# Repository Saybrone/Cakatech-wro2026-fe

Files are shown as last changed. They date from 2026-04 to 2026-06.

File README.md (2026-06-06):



# Team Çakatech - WRO® 2026 Future Engineers

<table border="0">
  <tr border="0">
    <td width="70%"  border="0">
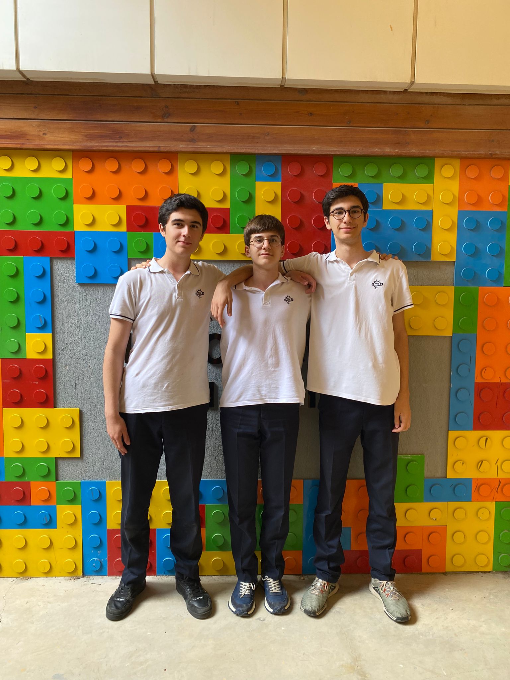
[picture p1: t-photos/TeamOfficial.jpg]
Official Photo
      
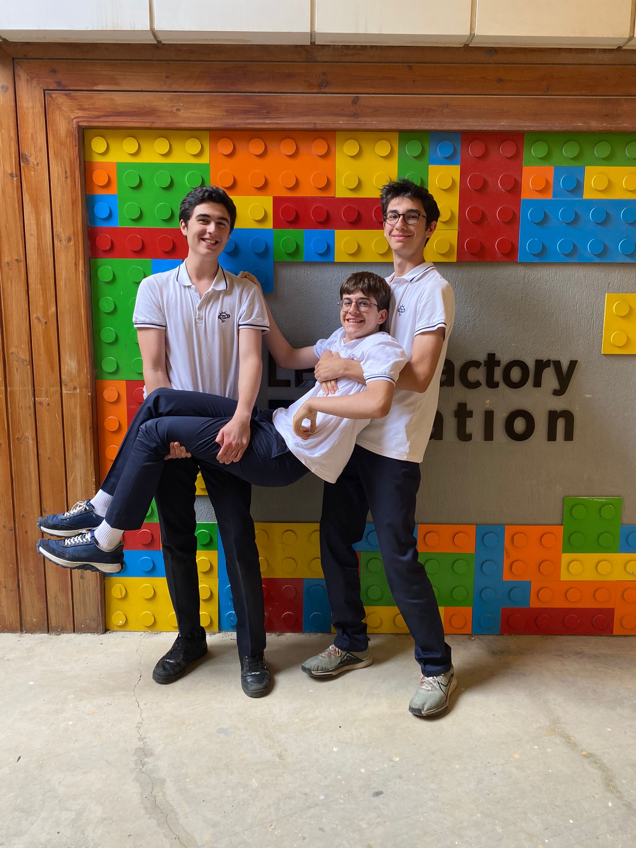
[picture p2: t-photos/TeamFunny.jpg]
Funny Photo
      
    </td>
    <td valign="top" style="padding-left: 0px;" border="0">
        This repository details team <em>Çakatech</em>'s building and programming process in the 2026 WRO Future Engineers Competition. 
      We are team <em>Çakatech</em>, three students who are passionate about technology and robotics. For this competition we built an autonomous vehicle. We worked after school and on weekends. Through this competition, we learned how to work as a team and solve problems related to robotics.
       </p>
        <strong>Team Members:</strong>
      <ul>
        <li>Batuhan Pekcan, 16</li>
        <li>Deniz Türker, 16</li>
        <li>Ali Aslan İşkol, 15</li>
      </ul>
      </p>
    </td>
  </tr>
</table>



# Table of Contents
- [Folder Contents](#folder-contents)
- [The Challenge](#the-challenge)
- [Vehicle Overview](#vehicle-overview)
  - [V-Photos](#v-photos)
  - [Hardware Components](#hardware-components)
  - [Electronic Components](#electronic-components)
  - [Mobility Management](#mobility-management)
    - [Powertrain](#powertrain)
    - [Steering](#steering)
    - [Chassis](#chassis)
- [Power and Sense Management](#power-and-sense-management)
  - [Li-ion Battery](#li-ion-battery)
  - [IMU Sensor](#imu-sensor)
  - [OpenMV Cam RT1062](#camera)
  - [EVN Alpha](#evn-alpha)
- [Software Components](#software-components)
  - [EVN Alpha Side](#evnalpha-side)
  - [OpenMV Camera Side](#openmv-side)
- [License](#license)

# Folder Contents 
* `models` is for the 3D files we used to print our parts
* `other` includes other files which can be used to understand how to prepare the vehicle for the competition. It includes documentations, datasets, hardware specifications, communication protocols,  descriptions etc.
* `schemes` contains schematic diagrams of the electromechanical components illustrating all the elements (electronic components and motors) used in the vehicle and how they connect to each other.
* `src` contains code of control software for all components which were programmed to participate in the competition
* `t-photos` contains photos of the team and logos
* `v-photos` contains 6 photos of the vehicle from various angles
* `video` contains the video.md file with the link to our YouTube channel and the respective videos

# The Challenge 

In the **[WRO 2026 Future Engineers – Self-Driving Cars](https://wro-association.org/)** category, teams are tasked with creating a robotic vehicle that can autonomously navigate a changing racetrack. Each round introduces new track layouts, requiring vehicles to adapt in real time.
The competition highlights the full engineering process:

- **Vehicle Design**: Building a functional robot with electromechanical components and advanced steering or motion systems.
- **Obstacle Management**: Applying computer vision, sensor fusion, and motion planning to make real-time decisions.
- **Project Documentation**: Maintaining an engineering journal and sharing designs in a public GitHub repository.

Teams are judged on performance, innovation, reliability, and the clarity of their engineering process, encouraging creativity, teamwork, and STEM skills.

Learn more about the challenge [here](https://wro-association.org/wp-content/uploads/WRO-2026-Future-Engineers-Self-Driving-Cars-General-Rules.pdf).

# Vehicle 

## V-Photos <b class="anchor" id="v-photos"></a>
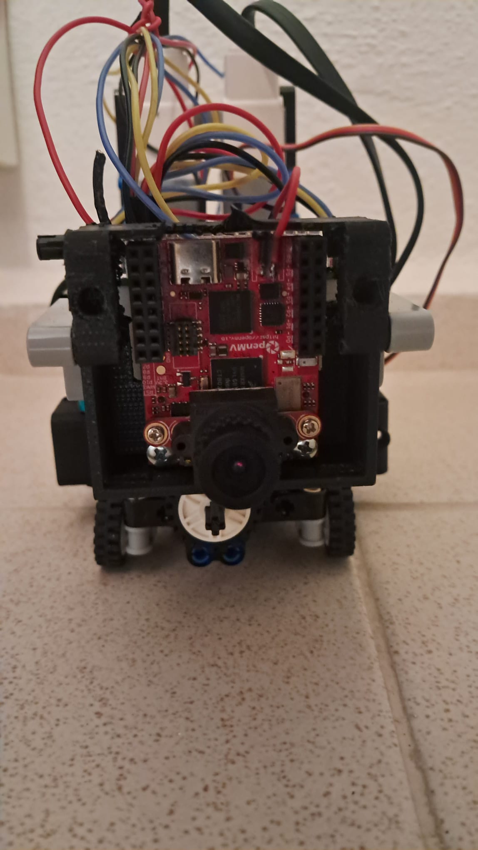
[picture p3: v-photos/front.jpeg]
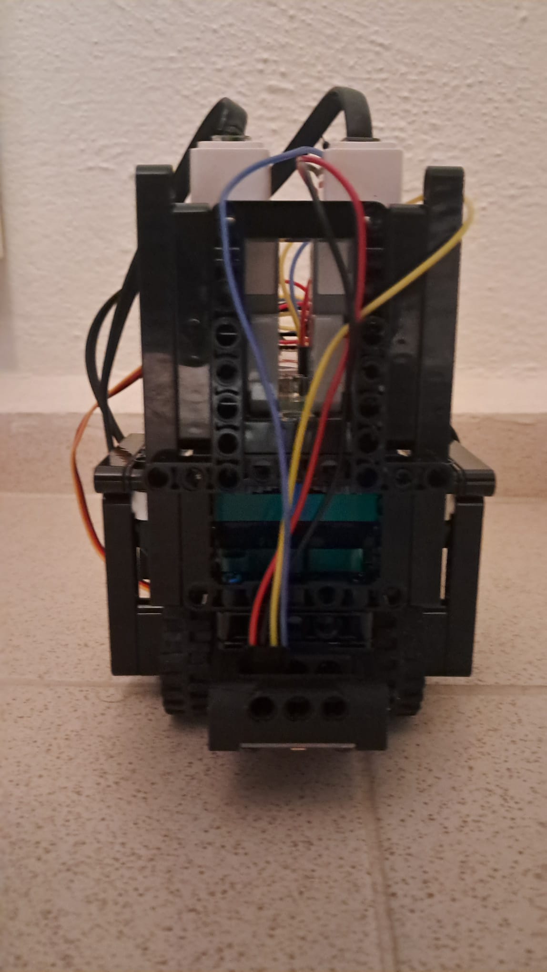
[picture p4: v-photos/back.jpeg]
|  |  | 
| :--: | :--: |
| *Front* | *Back* |
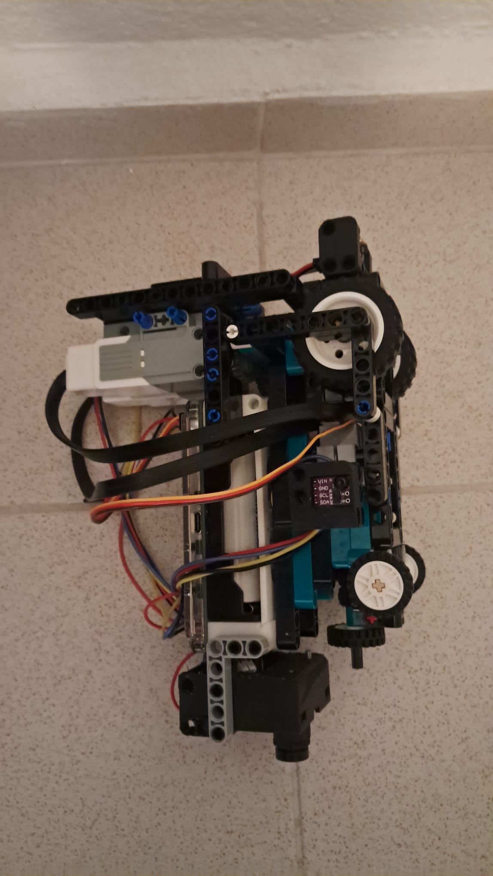
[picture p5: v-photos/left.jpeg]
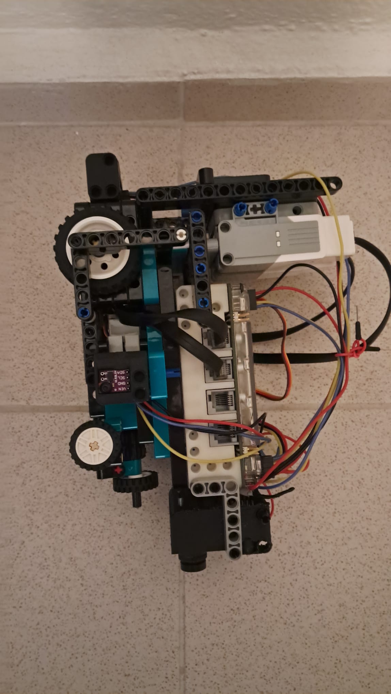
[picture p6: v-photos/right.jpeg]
|  |  | 
| *Left* | *Right* |
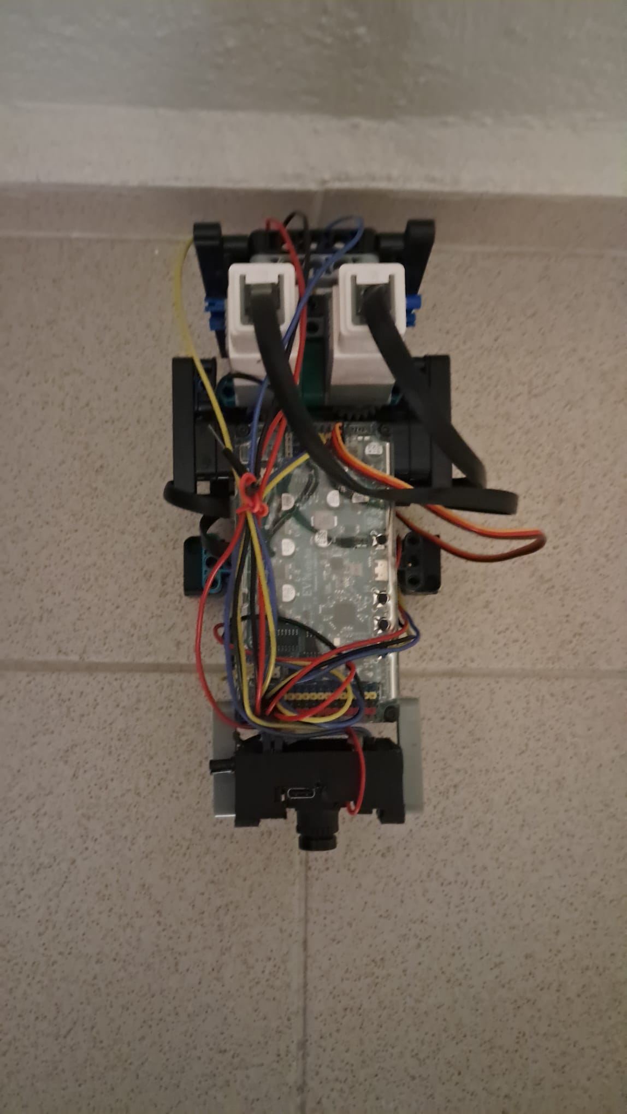
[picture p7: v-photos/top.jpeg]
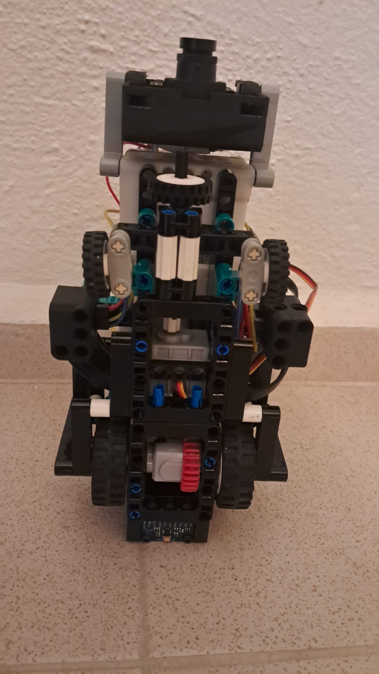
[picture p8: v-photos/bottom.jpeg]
|  |  | 
| *Top* | *Bottom* |

<br>

# Hardware Components 
This section covers all the parts utilized in the vehicle, such as motors, sensors, controllers, chassis, mechanical systems, and other components.
## Electronic Components 
<table border="1" cellpadding="12" cellspacing="0">
  <thead>
    <tr>
      <th>Component</th>
      <th>Description / Link</th>
      <th>Image</th>
      <th>Price</th>
    </tr>
  </thead>
  <tbody>
    <tr>
      <td>Motor</td>
      <td>EV3 Medium Motor</td>
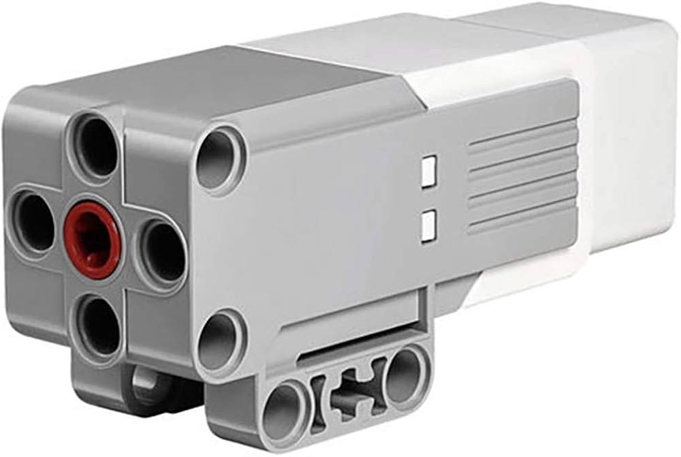
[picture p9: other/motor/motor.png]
Motor
      <td>
      <td>$125x2</td>
    </tr>
    <tr>
      <td>Servo Motor</td>
      <td>GeekServo (360 degrees)</a></td>
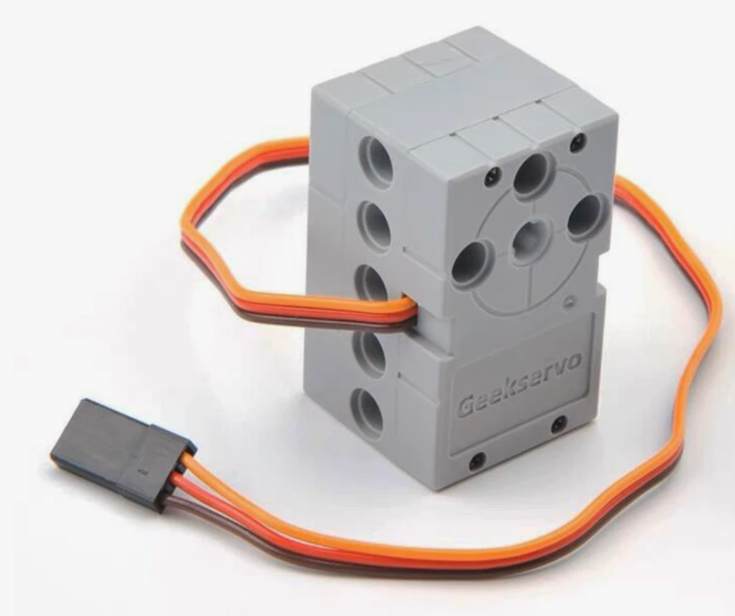
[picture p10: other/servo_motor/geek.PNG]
Servo motor
      <td>
      <td>$10</td>
    </tr>
  <tr>
    <tr>
      <td>Motor Controller and Processor</td>
      <td>EVN Alpha</a></td>
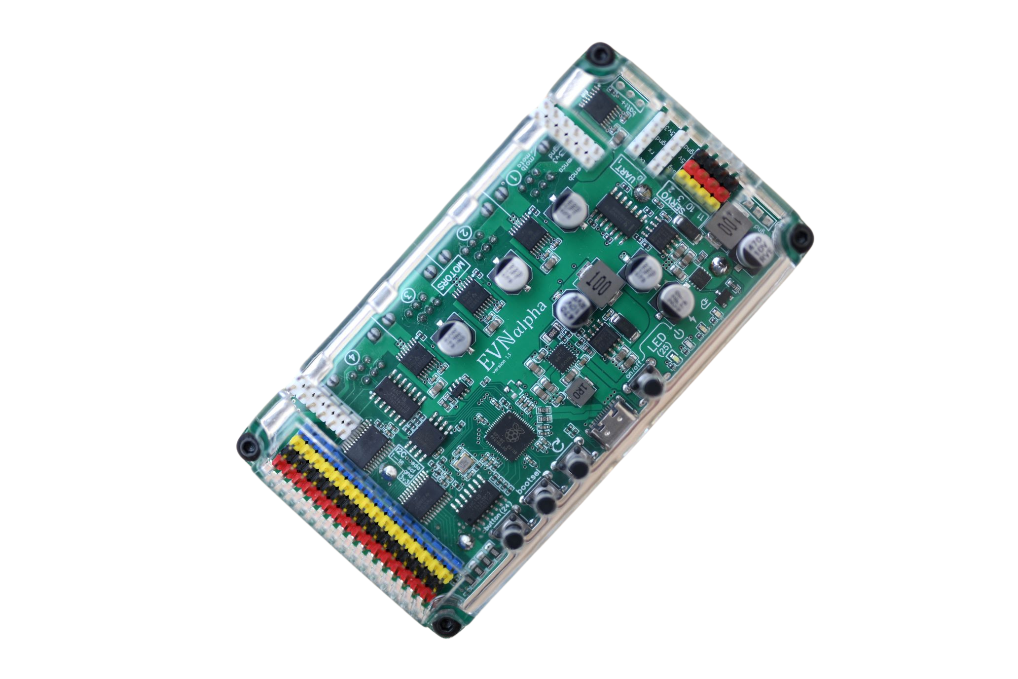
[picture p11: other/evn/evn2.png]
evn
      <td></td>
      <td>$168</td>
    </tr>
      <td>IMU</td>
      <td>MPU 6500 Gyro Sensor</td>
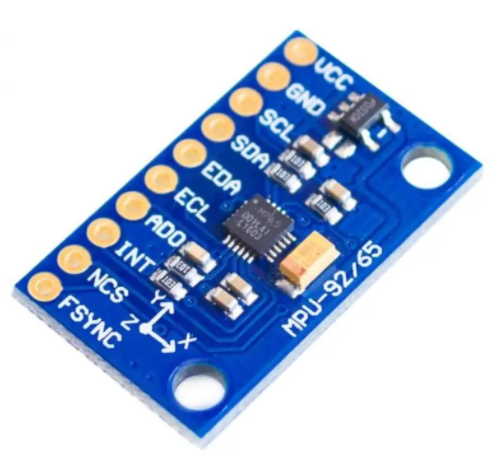
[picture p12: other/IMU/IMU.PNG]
IMU
      <td>
      <td>$1.88</td> 
    <tr>
      <td>Battery</td>
      <td>Molicel 35A Li-ion battery</td>
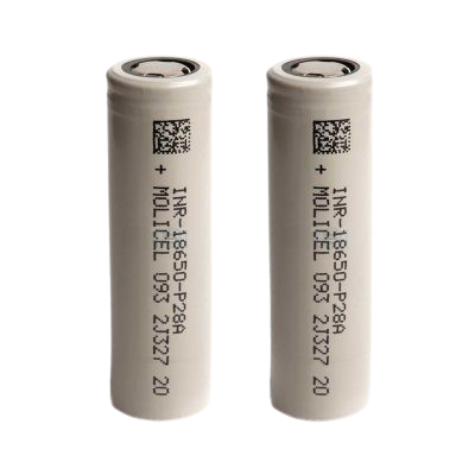
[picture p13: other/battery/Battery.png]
battery
      <td>
      <td>$10x2</td>
    </tr>
    </tr>
    <tr>
      <td>Camera</td>
      <td>OpenMV Cam RT1062</a></td>
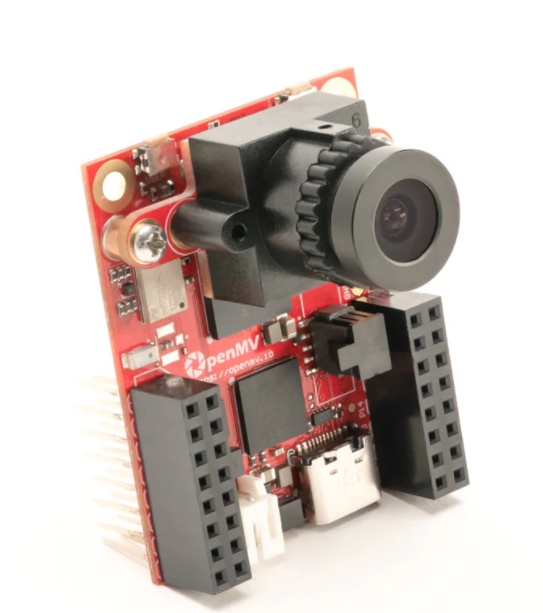
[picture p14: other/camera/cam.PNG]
Camera
      <td>
      <td>$120</td>
    </tr>
    <tr>
      <td>Time of Flight Sensors</td>
      <td>VL53L0X ToF Distance Sensor</a></td>
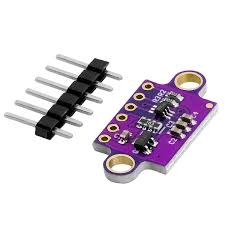
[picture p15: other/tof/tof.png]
Time of Flight
      <td>
      <td>$2.66x2</td>
    </tr>
    <tr>
      <td>Lego Differential</td>
      <td>Lego Differential</td>
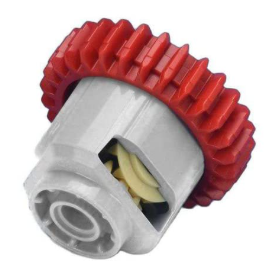
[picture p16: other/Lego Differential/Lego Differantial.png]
Differential
      <td>
      <td>$2.96</td> 
    <tr>
      <td colspan="3"><strong>Total Cost</strong></td>
      <td><strong>$878.06</strong></td>
    </tr>
  </tbody>
</table>

## Mobility Management 

Our robot’s mobility depends on the coordination of its powertrain, steering system, and chassis. Together, these components provide stability, control, and efficiency, enabling smooth and reliable movement.

### Powertrain 
The powertrain converts electrical energy into mechanical motion, driving the robot’s wheels for movement and obstacle navigation.

#### Motor
<table>
<tr>
<td>
EV3 Medium Motor
</td>

<td valign="top" style="padding-left: 15px;">

<b>Specifications (per motor):</b><br>
Rated Voltage: 9V<br>
Weight: 80g<br>
No-Load Speed: ~240 RPM<br>
Stall Torque: ~8 N·cm<br>
Integrated Rotation Sensor: 1° Resolution<br>
Connector: LEGO EV3/RJ12<br>
<br>
This project uses <b>two LEGO EV3 Medium Motors</b> as the primary actuators. These motors are designed for applications requiring <b>precise control</b> and <b>fast response</b>, making them ideal for robotic mechanisms and mobile platforms.
<br><br>
The built-in <b>high-resolution rotation sensor</b> enables accurate position and speed feedback, allowing for reliable closed-loop control. This feature is particularly useful for tasks that require precise movements, such as navigation and steering.
<br><br>
</td>
</tr>
</table>

#### Differential
<table> <tr><td> Differential<td valign="top" style="padding-left: 15px;"> <b>Specifications:</b><br> Dimensions: 23 x 16 x 11 cm <br> Weight: 18 g <br><br>This Lego Differential is fully compatible with 3D shapes and Lego parts, allowing for seamless integration. It also features a 28 Teeth Differential Gear with a round axle design, providing smooth rotational movement for our robot. </td> </tr> </table>

### Steering 
Our robot uses a **Ackermann steering** where the wheels are turned with linkage geometry. This method makes the robot easier to turn and keeps the overall design compact. It is highly effective for lightweight and fast-moving prototypes where simplicity and space efficiency are key.

#### Servo Motor
<table> <tr><td>Servo motor <td valign="top" style="padding-left: 15px;"> <b>Specifications:</b><br> Operating Voltage: 3.3V~6V<br> Rated Voltage: 4.8V<br> Rotational range: 360°<br> Maximum Torque: 1.6kg±0.2kg/cm (4.8V)<br> Maximum Speed: 45rpm (3V)<br> Weight: 20g<br><br> For steering we selected the <b>GeekServo</b>. This motor is compatible with Lego Technic parts and offers a higher speed compared to 9g motors. The output shaft features a Lego Technic axle connector, making it ideal for applications that require a high-power drive. </td> </tr> </table> 

### Chassis 
Our chassis combines LEGO components with custom 3D-printed parts, creating a reliable and durable structure. The chassis provides mounting points for all motors, controllers, and sensors, ensuring stable alignment and easy integration. Below, 3D models of the parts are included.

#### OpenMV Backpack
</p> <img src="/models/backpackOpenMV/backpackOpenMV.jpeg" alt = "OpenMV Backpack" width = "500" display:block; margin:0 auto; width:400px;" />

[3D Model](/models/backpackOpenMV/backpackOpenMV.stl)
#### **An updated version from [Instructables by CEEOInnovations](https://www.instructables.com/Backpack-1-OpenMV-Camera/)**
#### Electronic Diagram
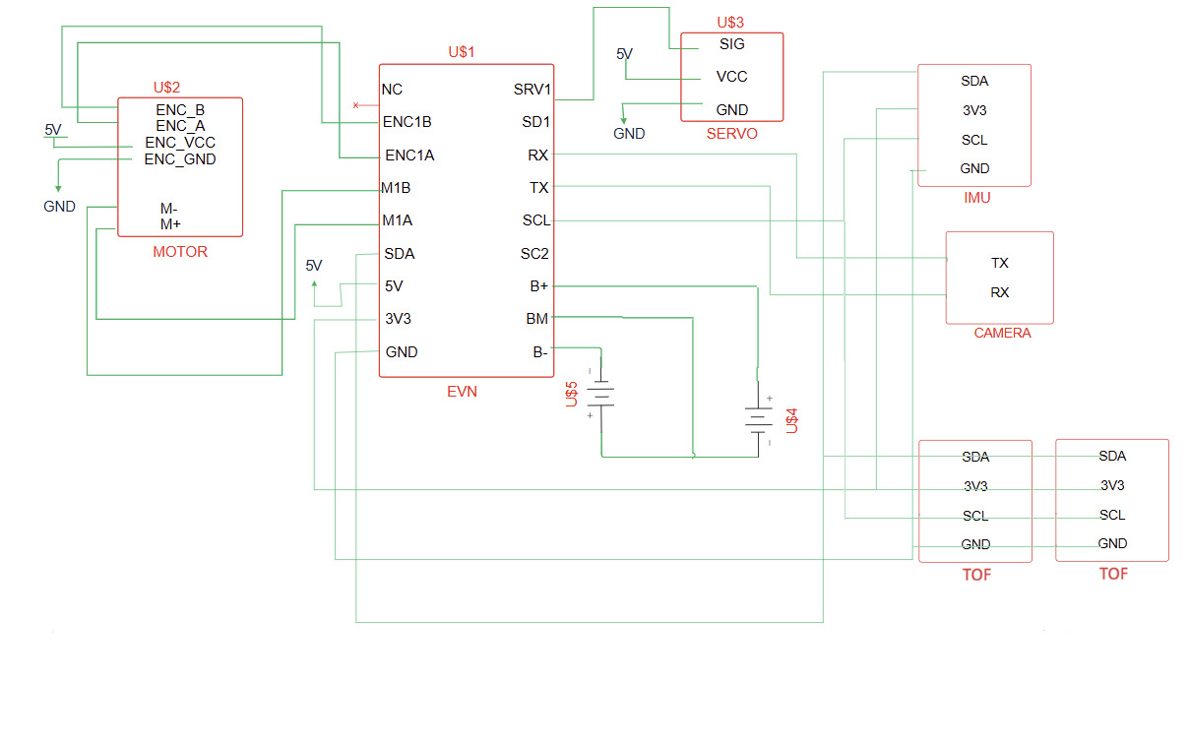
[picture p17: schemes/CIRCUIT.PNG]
schematic
</p> 
       
## Power and Sense Management 

### Li-ion Battery 
<table> <tr><td> Battery<td valign="top" style="padding-left: 15px;"> <b>Specifications:</b><br> Voltage: 3.7V <br>Capacity:2800mAh<br> Diameter: 18mm <br> Length: 65mm <br></td> </tr> </table> 

### IMU 
<table> <tr><td> IMU <b>Specifications:</b><br> Gyroscope Range: ±250, ±500, ±1000, ±2000 °/s<br>Accelerometer Range: ±2g, ±4g, ±8g, ±16g<br> Interface : I2C <br>Power Supply: 3.5V  <br> </td> </tr> </table> The MPU-6500 is a 6-axis MotionTracking sensor that combines a 3-axis gyroscope and a 3-axis accelerometer in a compact 3x3x0.9 mm package. This integration allows reliable motion detection and orientation tracking with reduced size and complexity. We selected the MPU-6500 because it provides reliable motion tracking, low power consumption, and small form factor, making it well-suited for our vehicle’s navigation and stability control.

### OpenMV Cam RT1062 
<table> <tr> <td><img src="other/camera/cam.PNG" alt = "Camera " width = "800" width:800px; height:auto; display:block; margin:0 auto;" />
 </td> <td valign="top" style="padding-left: 15px;"> <b>Specifications:</b><br> Microcontroller: ARM Cortex M7 (RT1062)<br>Frequency: 600 MHz<br> RAM: 32 MB SDRAM + 1 MB SRAM <br> Flash Memory: 16 MB program/storage flash<br>Camera Resolution: 2592 × 1944 (5 MP) <br> Frame Rate:~40 FPS on QVGA (320 × 240) <br><br> This <b>OpenMV Cam -RT1062</b> is the one we used in our robot. The OpenMV Cam is a small, low-power microcontroller board that we used in our robot to implement machine vision applications. We program the OpenMV Cam in high-level Python scripts (via the MicroPython Operating System) instead of C/C++, which makes it much easier to handle the complex outputs of machine vision algorithms and work with high-level data structures. At the same time, we retain full control over the OpenMV Cam and its I/O pins in Python. This allows our robot to locate obstacles, lines and walls, enabling intelligent, autonomous behaviors. </td> </tr> </table>

### EVN Alpha 
<table> <tr> <td><img src="other/evn/evn alpha2.jpg" alt = "evn alpha" width = "1100"  width:800px; height:auto; display:block; margin:0 auto;" />
 </td> <td valign="top" style="padding-left: 15px;"> <b>The EVN ALPHA is a compact robot controller based on the RP2040, housed in a LEGO Technic-compatible shell. It provides 26 I/O channels for controlling brushed DC motors, servos, and connecting UART or I2C peripherals. The board also integrates a 2-cell Lithium-Ion power management system, offering charging, cell balancing, and voltage regulation, making it ideal for safely powering and controlling our robot’s motors and sensors.</td> </tr> </table>
   
## Software Components 
### EVN Alpha Side 
```ino
#include <EVN.h>
#include <SoftwareSerial.h>
#include <math.h>

// -----------------------------------------------------------------------
// Port assignments
// -----------------------------------------------------------------------
#define SERVO_DIR_PORT        1
#define IMU_I2C_PORT          1
#define TOF_LEFT_PORT         3
#define TOF_RIGHT_PORT        2
#define PPR_VALUE             2200

// -----------------------------------------------------------------------
// Servo positions
// -----------------------------------------------------------------------
const float SERVO_CENTER = 133;
const int   SERVO_RIGHT  = 70;
const int   SERVO_LEFT   = 210;

// -----------------------------------------------------------------------
// Turn PD tuning
// -----------------------------------------------------------------------
#define TURN_KP               16.0f
#define TURN_KD               0.8f
#define TURN_SPEED_MAX        1000
#define TURN_SPEED_MIN        400
#define TURN_TOLERANCE        1.0f

// -----------------------------------------------------------------------
// Straight drive PD tuning
// -----------------------------------------------------------------------
#define STRAIGHT_KP           8.0f
#define STRAIGHT_KD           0.4f
#define STRAIGHT_SPEED        1000
#define STRAIGHT_DISTANCE_CM  50.0f

// -----------------------------------------------------------------------
// Wall / proximity config
// -----------------------------------------------------------------------
#define WALL_FOLLOW_SPEED     800
#define WALL_KP               0.5f
#define WALL_KD               0.02f
#define WALL_MAX_CORRECTION   60.0f
#define NO_WALL_MM            10000.0f
#define WALL_TOO_CLOSE_MM     50.0f
#define WALL_CLOSE_KP         1.2f
#define WALL_CLOSE_KD         0.05f
// -----------------------------------------------------------------------
// Pillar avoidance config
// -----------------------------------------------------------------------
// When a pillar error (pixels from center) exceeds this, start correcting
#define PILLAR_ERROR_THRESHOLD   300
// How strongly to steer toward correct side per pixel of error
#define PILLAR_STEER_KP          3.5f
// Minimum pillar area (pixels^2) to act on — filters distant/noise blobs
#define PILLAR_MIN_AREA          50
// Speed while actively avoiding a pillar
#define PILLAR_AVOID_SPEED       800
// Normal cruising speed between pillars
#define CRUISE_SPEED             800

// -----------------------------------------------------------------------
// Lap / direction config
// -----------------------------------------------------------------------
// Total corners to navigate for 3 laps
#define TOTAL_CORNERS            12
// Brightness threshold: below this means wall (corner) detected
#define BRIGHTNESS_WALL_THRESH   30.0f

// -----------------------------------------------------------------------
// OpenMV UART
// -----------------------------------------------------------------------
#define OPENMV_RX_PIN  1
#define OPENMV_TX_PIN  0
#define UART_TIMEOUT   500

// -----------------------------------------------------------------------
// Wheel geometry
// -----------------------------------------------------------------------
#define WHEEL_DIAMETER_MM     43.2f
#define GEAR_RATIO            1.0f

// -----------------------------------------------------------------------
// Hardware objects
// -----------------------------------------------------------------------
EVNAlpha          board;
EVNMotor          motor_left(1, EV3_MED);
EVNMotor          motor_right(2, EV3_MED);
EVNServo          steeringServo(SERVO_DIR_PORT);
EVNIMUSensor      imu(IMU_I2C_PORT);
EVNDistanceSensor tof_left(TOF_LEFT_PORT);
EVNDistanceSensor tof_right(TOF_RIGHT_PORT);
SoftwareSerial    openmv(OPENMV_RX_PIN, OPENMV_TX_PIN);
int locked_turn_dir = 0;
// -----------------------------------------------------------------------
// Shared gyro state
// -----------------------------------------------------------------------
volatile float yaw_angle = 0.0f;

// -----------------------------------------------------------------------
// Driving direction: +1 = clockwise (orange seen first, turn right = +90)
//                   -1 = counter-clockwise (blue seen first, turn left = -90)
// -----------------------------------------------------------------------
int drive_direction = 0;  // determined at start

// -----------------------------------------------------------------------
// setup / setup1
// -----------------------------------------------------------------------
void setup() {
  Serial.begin(9600);
  board.begin();
  board.setLinkLED(true);
  board.setMode(BUTTON_TOGGLE);
  imu.begin();
  imu.setGyroRange(IMU_GYRO_DPS_1000);
  tof_left.begin();
  tof_right.begin();
  openmv.begin(9600);
  delay(1000);
}

void setup1() {
  motor_left.begin();
  motor_right.begin();
  steeringServo.begin();
  steeringServo.write(SERVO_CENTER);
}

// -----------------------------------------------------------------------
// getYaw — fixed-rate gyro integration
// -----------------------------------------------------------------------
float getYaw() {
  static unsigned long last_us = micros();

  while ((micros() - last_us) < 2000UL);
  unsigned long now = micros();
  float dt = (now - last_us) / 1000000.0f;
  last_us = now;

  float gz = imu.readGyroZ();
  if (fabs(gz) < 0.1f) gz = 0;

  float y = yaw_angle + gz * dt;
  if (y >  180.0f) y -= 360.0f;
  if (y < -180.0f) y += 360.0f;
  yaw_angle = y;
  return yaw_angle;
}
void turnByDegreeReverse(float start_degree, float target_degrees,
                         int speed_min   = TURN_SPEED_MIN,
                         int speed_max   = TURN_SPEED_MAX,
                         float kp        = TURN_KP,
                         float kd        = TURN_KD,
                         float tolerance = TURN_TOLERANCE) {

  float goal_yaw = start_degree + target_degrees;
  float error = goal_yaw - getYaw();
  float prev_error = error;

  // Reverse steering logic
  steeringServo.write(error > 0 ? SERVO_LEFT : SERVO_RIGHT);
  delay(200);

  while (fabs(error) > tolerance) {

    prev_error = error;

    error = goal_yaw - getYaw();
    if (error > 180.0f) error -= 360.0f;
    if (error < -180.0f) error += 360.0f;

    float derivative = error - prev_error;

    int speed = (int)constrain(
      fabs(kp * error + kd * derivative),
      (float)speed_min,
      (float)speed_max
    );

    // Steering reversed because car is backing up
    steeringServo.write(error > 0 ? SERVO_LEFT : SERVO_RIGHT);

    motor_left.runSpeed(-speed);
    motor_right.runSpeed(-speed);
  }

  steeringServo.write(SERVO_CENTER);
  motor_left.runSpeed(0);
  motor_right.runSpeed(0);
}
// -----------------------------------------------------------------------
// turnByDegree — PD, full servo lock
// -----------------------------------------------------------------------
void turnByDegree(float start_degree, float target_degrees,
                  int speed_min   = TURN_SPEED_MIN,
                  int speed_max   = TURN_SPEED_MAX,
                  float kp        = TURN_KP,
                  float kd        = TURN_KD,
                  float tolerance = TURN_TOLERANCE) {

  float goal_yaw   = start_degree + target_degrees;
  float error = goal_yaw - getYaw();
  float prev_error = error;

  steeringServo.write(error > 0 ? SERVO_RIGHT : SERVO_LEFT);
  delay(200);

  while (fabs(error) > tolerance ) {
    prev_error = error;
    error = goal_yaw - getYaw();
    if (error >  180.0f) error -= 360.0f;
    if (error < -180.0f) error += 360.0f;

    float derivative = error - prev_error;
    int speed = (int)constrain(
      fabs(kp * error + kd * derivative),
      (float)speed_min,
      (float)speed_max
    );

    steeringServo.write(error > 0 ? SERVO_RIGHT : SERVO_LEFT);
    motor_left.runSpeed(speed);
    motor_right.runSpeed(speed);
  }

  steeringServo.write(SERVO_CENTER);
  motor_left.runSpeed(0);
  motor_right.runSpeed(0);
}
int timeout = 500;
// -----------------------------------------------------------------------
// driveStraight — PD, encoder distance
// -----------------------------------------------------------------------
void driveStraight(float start_degree,
                   int   drive_speed = STRAIGHT_SPEED,
                   float distance_cm = STRAIGHT_DISTANCE_CM,
                   float kp          = STRAIGHT_KP,
                   float kd          = STRAIGHT_KD,
                   float gear_ratio  = GEAR_RATIO) {

  float wheel_circ_cm = PI * (WHEEL_DIAMETER_MM / 10.0f);
  float target_ticks  = (distance_cm / wheel_circ_cm) * gear_ratio * PPR_VALUE;

  long start_left  = motor_left.getPosition();
  long start_right = motor_right.getPosition();
  float prev_error = 0.0f;

  while (true) {
    float travelled = (fabs(motor_left.getPosition()  - start_left) +
                       fabs(motor_right.getPosition() - start_right)) / 2.0f;
    if (travelled >= target_ticks) break;

    float error = getYaw() - start_degree;
    if (error >  180.0f) error -= 360.0f;
    if (error < -180.0f) error += 360.0f;

    float derivative = error - prev_error;
    prev_error = error;

    float servo_pos = constrain(
      SERVO_CENTER + kp * error + kd * derivative,
      (float)SERVO_RIGHT,
      (float)SERVO_LEFT
    );

    steeringServo.write(servo_pos);
    motor_left.runSpeed(drive_speed);
    motor_right.runSpeed(drive_speed);
  }

  steeringServo.write(SERVO_CENTER);
  motor_left.runSpeed(0);
  motor_right.runSpeed(0);
}

// -----------------------------------------------------------------------
// OpenMV communication helpers
// -----------------------------------------------------------------------
char m[100];
String readMessage() {
  bool started = false;
  int i = 0;
  unsigned long startTime = millis();

  while (true) {
    getYaw();
    if (openmv.available() > 0) {
      char c = openmv.read();
      if (c == '<') {
        started = true;
        i = 0;
      } else if (c == '*' && started) {
        m[i] = '\0';
        String result = String(m);
        Serial.println(result);
        openmv.write('0');
        return result;
      } else if (started && i < (int)sizeof(m) - 1) {
        m[i++] = c;
      }
    }
    if (millis() - startTime > timeout) return "";
  }
}

String requestGreen() {
  openmv.write('1');
  return readMessage();
}

String requestRed() {
  openmv.write('2');
  return readMessage();
}

String requestBrightness() {
  openmv.write('3');
  String msg = readMessage();
  if (msg == "") msg = "100";
  return msg;
}

String requestOrange() {
  openmv.write('4');
  String msg = readMessage();
  if (msg == "") msg = "False";
  return msg;
}

String requestBlue() {
  openmv.write('5');
  String msg = readMessage();
  if (msg == "") msg = "False";
  return msg;
}

// -----------------------------------------------------------------------
// parsePillarResponse
// Parses OpenMV response like "[3200, -45]?[1800, 12]?" into the
// largest-area blob's area and pixel error from center.
// Returns false if no valid blob found.
// -----------------------------------------------------------------------
bool parsePillarResponse(String response, int &area, int &error) {
  area  = 0;
  error = 0;

  if (response.length() == 0) return false;

  int best_area  = 0;
  int best_error = 0;
  bool found = false;

  int idx = 0;
  while (idx < (int)response.length()) {
    int open  = response.indexOf('[', idx);
    int close = response.indexOf(']', idx);
    if (open < 0 || close < 0) break;

    String entry = response.substring(open + 1, close);
    int comma = entry.indexOf(',');
    if (comma > 0) {
      int a = entry.substring(0, comma).toInt();
      int e = entry.substring(comma + 1).toInt();
      if (a > best_area) {
        best_area  = a;
        best_error = e;
        found = true;
      }
    }
    idx = close + 1;
  }

  if (found) {
    area  = best_area;
    error = best_error;
  }
  return found;
}

// -----------------------------------------------------------------------
// detectDirection
// Determines CW (+1) or CCW (-1) by looking for orange or blue line.
// Drives slowly forward until a line is seen.
// Returns +1 (orange/clockwise) or -1 (blue/counter-clockwise).
// -----------------------------------------------------------------------
int detectDirection() {
  float start_yaw = getYaw();

  while (true) {
    float error = getYaw() - start_yaw;
    if (error >  180.0f) error -= 360.0f;
    if (error < -180.0f) error += 360.0f;

    steeringServo.write(constrain(
      SERVO_CENTER + STRAIGHT_KP * error,
      (float)SERVO_RIGHT,
      (float)SERVO_LEFT
    ));
    motor_left.runSpeed(400);
    motor_right.runSpeed(400);

    if (requestOrange() == "True") {
      motor_left.runSpeed(0);
      motor_right.runSpeed(0);
      return 1;
    }
    if (requestBlue() == "True") {
      motor_left.runSpeed(0);
      motor_right.runSpeed(0);
      return -1;
    }
  }
}

// -----------------------------------------------------------------------
// avoidPillar
// Called when a pillar is visible ahead.
// Red pillar:   must pass to the RIGHT of robot → steer left to go around
// Green pillar: must pass to the LEFT of robot  → steer right to go around
//
// error from OpenMV: negative = pillar is left of camera center
//                    positive = pillar is right of camera center
void avoidPillar(bool is_red, int pillar_error, float heading) {
  unsigned long start_ms = millis();

  while (true) {
    String response = is_red ? requestRed() : requestGreen();
    int area = 0, px_error = 0;
    bool visible = parsePillarResponse(response, area, px_error);

    if (!visible || area < PILLAR_MIN_AREA) break;
    if (millis() - start_ms > 3000) break;

    float correction;
    if (is_red) {
      // RED: push pillar to the right → steer left (negative correction)
      correction = PILLAR_STEER_KP * (-PILLAR_ERROR_THRESHOLD - px_error);
    } else {
      // GREEN: push pillar to the left → steer right (positive correction)
      correction = PILLAR_STEER_KP * (PILLAR_ERROR_THRESHOLD - px_error);
    }

    // Wall avoidance on top of pillar steering
    float dist_left  = tof_left.read();
    float dist_right = tof_right.read();

    if (dist_left > 0 && dist_left < WALL_TOO_CLOSE_MM) {
      correction += WALL_CLOSE_KP * (WALL_TOO_CLOSE_MM - dist_left);   // steer right
    } else if (dist_right > 0 && dist_right < WALL_TOO_CLOSE_MM) {
      correction -= WALL_CLOSE_KP * (WALL_TOO_CLOSE_MM - dist_right);  // steer left
    }

    // Light gyro heading hold
    float gyro_err = getYaw() - heading;
    if (gyro_err >  180.0f) gyro_err -= 360.0f;
    if (gyro_err < -180.0f) gyro_err += 360.0f;

    float servo_pos = constrain(
      SERVO_CENTER + correction + STRAIGHT_KP * gyro_err * 0.3f,
      (float)SERVO_RIGHT, (float)SERVO_LEFT
    );

    steeringServo.write(servo_pos);
    motor_left.runSpeed(PILLAR_AVOID_SPEED);
    motor_right.runSpeed(PILLAR_AVOID_SPEED);
  }
}
// For RED (pass on right):
//   We want the pillar to end up on our right → steer LEFT (negative servo)
//   Target: keep error > +threshold (pillar stays right of center)
//
// For GREEN (pass on left):
//   We want the pillar to end up on our left → steer RIGHT (positive servo)
//   Target: keep error < -threshold (pillar stays left of center)
// -----------------------------------------------------------------------
bool checkAndAvoidPillar1(float heading) {
    // Get red detection
    String redResp = requestRed();
    int redArea = 0, redPxErr = 0;
    bool redDetected =
        parsePillarResponse(redResp, redArea, redPxErr) &&
        redArea >= PILLAR_MIN_AREA;

    // Get green detection
    String greenResp = requestGreen();
    int greenArea = 0, greenPxErr = 0;
    bool greenDetected =
        parsePillarResponse(greenResp, greenArea, greenPxErr) &&
        greenArea >= PILLAR_MIN_AREA;

    // Nothing detected
    if (!redDetected && !greenDetected) {
        return false;
    }

    // Choose the larger pillar
    if (redDetected && (!greenDetected || redArea >= greenArea)) {
        Serial.println("RED pillar selected (larger area), passing on right");

        avoidPillar(true, redPxErr, heading);

        driveStraight(heading, 800, 3.0, 0.5, 0.01, 1);
        turnByDegree(0, heading);
        delay(1000);
        driveStraight(heading,800,2,0.5,0.01,1);
        turnByDegree(0, heading - 60);
        turnByDegree(0, heading);

        return true;
    }

    // Green must be larger
    Serial.println("GREEN pillar selected (larger area), passing on left");

    avoidPillar(false, greenPxErr, heading);

    driveStraight(heading, 800, 3.0, 0.5, 0.01, 1);
    turnByDegree(0, heading);
    delay(1000);
    driveStraight(heading,800,2,0.5,0.01,1);
    turnByDegree(0, heading + 60);
    turnByDegree(0, heading);

    return true;
}
// -----------------------------------------------------------------------
// driveUntilCorner
// Drives forward avoiding any visible pillars until the camera detects
// a wall ahead (brightness < threshold), then stops.
// Returns immediately so the caller can do the corner turn.
// -----------------------------------------------------------------------
void driveUntilDark(float start_degree,
                    bool is_back=false,
                    int   corner_count  = 1,
                    int   speed         = WALL_FOLLOW_SPEED,
                    float bright_thresh = BRIGHTNESS_WALL_THRESH,
                    float too_close_mm  = WALL_TOO_CLOSE_MM,
                    float close_kp      = WALL_CLOSE_KP,
                    float gyro_kp       = STRAIGHT_KP,
                    float gyro_kd       = STRAIGHT_KD,
                    float close_kd      = WALL_CLOSE_KD) {

  float prev_gyro_error  = 0.0f;
  float prev_close_error = 0.0f;

  while (true) {
    // --- Brightness check ---
    String bright_str = requestBrightness();
    float brightness = bright_str.toFloat();
    String redResp = requestRed();
    int redArea = 0, redPxErr = 0;

    String greenResp = requestGreen();
    int greenArea = 0, greenPxErr = 0;

    bool redDetected =parsePillarResponse(redResp, redArea, redPxErr) && redArea >= PILLAR_MIN_AREA;
    bool greenDetected = parsePillarResponse(greenResp, greenArea, greenPxErr) && greenArea >= PILLAR_MIN_AREA;

    if (brightness < bright_thresh && !redDetected && !greenDetected) {
      motor_left.runSpeed(0);
      motor_right.runSpeed(0);
      steeringServo.write(SERVO_CENTER);

      // First corner: decide direction from ToF
      if (locked_turn_dir == 0) {
        float dist_left  = tof_left.read();
        float dist_right = tof_right.read();
        if (dist_left  <= 0) dist_left  = 0;
        if (dist_right <= 0) dist_right = 0;
        locked_turn_dir = (dist_left >= dist_right) ? -1 : 1;
      }

      // Turn to absolute heading: corner_count * 90 from origin (0)
      if (is_back){
        turnByDegreeReverse(start_degree, locked_turn_dir * corner_count * 90.0f);
      }else{
        turnByDegree(start_degree, locked_turn_dir * corner_count * 90.0f);
      }
      return;
    }

    // --- ToF close-wall PD correction ---
    float dist_left  = tof_left.read();
    float dist_right = tof_right.read();
    float correction = 0.0f;

    if (dist_left > 0 && dist_left < too_close_mm) {
      float close_error      = too_close_mm - dist_left;
      float close_derivative = close_error - prev_close_error;
      prev_close_error       = close_error;
      correction = close_kp * close_error + close_kd * close_derivative;

    } else if (dist_right > 0 && dist_right < too_close_mm) {
      float close_error      = too_close_mm - dist_right;
      float close_derivative = close_error - prev_close_error;
      prev_close_error       = close_error;
      correction = -(close_kp * close_error + close_kd * close_derivative);

    } else {
      // --- Gyro straight-hold PD ---
      prev_close_error = 0.0f;
      float gyro_error      = getYaw() - start_degree - locked_turn_dir*(corner_count-1)*90;
      float gyro_derivative = gyro_error - prev_gyro_error;
      prev_gyro_error       = gyro_error;
      Serial.println(gyro_error);
      correction = -(gyro_kp * gyro_error + gyro_kd * gyro_derivative);
    }

    float servo_pos = constrain(
      SERVO_CENTER - correction,
      (float)SERVO_RIGHT, (float)SERVO_LEFT
    );

    steeringServo.write(servo_pos);
    motor_left.runSpeed(speed);
    motor_right.runSpeed(speed);
  }
}

void pass_line(float heading){
  String grn_resp = requestGreen();
  int area = 0, px_err = 0;
  checkAndAvoidPillar1(heading);
  checkAndAvoidPillar1(heading);
  driveUntilDark(heading,false);
  driveStraight(heading+locked_turn_dir*90,-800,3,0.5,0.01,1);
}
// -----------------------------------------------------------------------
// parkingSequence
// After 3 laps the robot needs to find and enter the parking lot.
// The parking lot is in the starting section; the robot drives back
// toward it using gyro, detects the magenta markers with the ToF sensors,
// and performs parallel parking:
//   1. Drive to align past the far marker
//   2. Turn into the lot
//   3. Reverse in
//   4. Straighten up parallel to the wall
// -----------------------------------------------------------------------
// -----------------------------------------------------------------------
bool button_output = false;

void loop() {
  button_output = board.buttonRead(); 
  if (button_output) {
    float heading = getYaw();
    driveUntilDark(heading,false);
    driveStraight(heading+locked_turn_dir*90,-800,4,0.5,0.01,1);
    for(int i = 1;i<=12;i++){
      pass_line(heading+locked_turn_dir*90*i);
      delay(1000);
    }

    motor_left.runSpeed(0);
    motor_right.runSpeed(0);
    while(true){
      delay(100);
    }

  } else {
    motor_left.runSpeed(0);
    motor_right.runSpeed(0);
  }
}
```
### OpenMV Camera Side 

#### 1. Color Detection
- **Orange / Blue line**:  
  - Detects blobs in bottom ROI.  
  - Returns `True` if blob is large enough.  
- **Red / Green box**:  
  - Detects rectangular blobs.  
  - Filters by size and shape.  
  - Returns `[area, error]` for EVN Alpha.  

#### 2. Brightness Detection
- Reads a central ROI.  
- Computes average brightness.  
- Low brightness → wall detected.  

#### 3. UART Control
- Waits for EVN Alpha command.  
- Runs appropriate detection function.  
- Sends results back wrapped in `<...*>`.  

Example:  
- EVN Alpha sends `1`.  
- Camera detects green box.  
- Camera replies: `<500,20*>` (area=500, error=20px right).
```py
import sensor, time
from machine import UART

sensor.reset()
sensor.set_pixformat(sensor.RGB565)
sensor.set_framesize(sensor.QVGA)
sensor.set_auto_gain(False)
sensor.set_auto_whitebal(False)
#---Flips sensor data because it is upside down---
sensor.set_vflip(True)
sensor.set_hmirror(True)

sensor.skip_frames(time=2000)
uart1 = UART(1, baudrate=9600) #Starts Uart Communication in pin "P4" and "P5"

clock = time.clock()
img_width = sensor.width()
img_height = sensor.height()

#---Finds brightness in middle to detect wall---
def Find_MiddleBrightness(img):
    #---Defining a rectangle roi for middle---
    rect_x = int(img_width * 0.3)
    rect_y = int(img_height * 0.35)
    rect_w = int(img_width * 0.4)
    rect_h = int(img_height * 0.3)
    middle_roi = (rect_x, rect_y, rect_w, rect_h)

    #---Gets the average brightness of the pixels in roi---
    stats = img.get_statistics(roi=middle_roi)
    brightness = stats.mean()
    return brightness

#---Detects Orange Line to determine the direction---
def Find_Orange_Line(img):
    orange_threshold = (40, 51, -115, 68, 16, 29) #Color threshold used for orange

    #---Defines a rectangle roi for the floor---
    rect_x = int(0)
    rect_y = int(img_height * 0.3)
    rect_w = int(img_width)
    rect_h = int(img_height)
    lines_roi = (rect_x, rect_y, rect_w, rect_h)

    #---Finds similar colored pixel blocks---
    orange_blobs = img.find_blobs([orange_threshold], roi=lines_roi, area_threshold=3000)
    for blob in orange_blobs:
        img.draw_rectangle(blob.rect(),color=(0, 255, 0))
        return True #Returns True if sees an orange blob
    return False #Returns False if it doesn't see an orange blob

#---Detects Blue Line to determine the direction---
def Find_Blue_Line(img):
    blue_threshold = (35, 8, -128, 16, -128, -6) #Color threshold used for blue

    #---Defines a rectangle roi for the floor---
    rect_x = int(0)
    rect_y = int(img_height * 0.3)
    rect_w = int(img_width)
    rect_h = int(img_height)
    lines_roi = (rect_x, rect_y, rect_w, rect_h)
    img.draw_rectangle(lines_roi,color=(255, 0, 0))

    #---Finds similar colored pixel blocks---
    blue_blobs = img.find_blobs([blue_threshold], roi=lines_roi, area_threshold=3000)
    for blob in blue_blobs:
        img.draw_rectangle(blob.rect(),color=(0, 255, 0))
        print(blob.area())
        return True #Returns True if sees a blue blob

    return False #Returns False if it doesn't see a blue blob

#---Detects Red Rectangles (used for object tracking or direction)---
def Find_Red_Rect(img):
    red_threshold = (9, 72, 57, 22, -12, 57) #Color threshold used for red
    blobs_red = img.find_blobs([red_threshold], area_threshold=1000)

    rect = None
    center = None
    error = None
    area = None
    returnSTR = ""

    #---Draws cross at image center---
    img_center_x = img.width() // 2
    img_center_y = img.height() // 2
    img.draw_cross(img_center_x, img_center_y, color=(255, 0, 0))

    #---Finds blobs that match red threshold---
    for a in blobs_red:
        img.draw_rectangle(a.rect())
        x, y, w, h = a.rect()
        img.draw_cross(x + w // 2, y + h // 2)

        #---Check shape (elongation close to rectangle)---
        if a.elongation() < 1.2:
            area = a.area()
            rect = a.rect()
            x, y, w, h = rect
            center = (x + w // 2, y + h // 2)
            error = center[0] - img_center_x
            returnSTR = returnSTR + str([area, error])+"?"

    return returnSTR

#---Detects Green Rectangles (used for object tracking or direction)---
def Find_Green_Rect(img):
    green_threshold = (0, 52, -35, -15, -55, 17) #Color threshold used for green
    blobs_green = img.find_blobs([green_threshold], area_threshold=1000)

    rect = None
    center = None
    returnSTR = ""
    error = 0
    area = 0

    #---Draws cross at image center---
    img_center_x = img.width() // 2
    img_center_y = img.height() // 2
    img.draw_cross(img_center_x, img_center_y, color=(255, 0, 0))

    #---Finds blobs that match green threshold---
    for a in blobs_green:
        img.draw_rectangle(a.rect())
        x, y, w, h = a.rect()
        img.draw_cross(x + w // 2, y + h // 2)

        #---Check shape (elongation close to rectangle)---
        if a.elongation() < 1.2:
            area = a.area()
            rect = a.rect()
            x, y, w, h = rect
            center = (x + w // 2, y + h // 2)
            error = center[0] - img_center_x
            returnSTR = returnSTR + str([area, error])+"?"

    return returnSTR

#---Main Loop---
while True:
    clock.tick()  #Updates the FPS clock
    img = sensor.snapshot()  #Takes a picture from the camera

    #---Reads 1 byte from UART to decide which function to run---
    a = uart1.read(1)

    if a == b'1':
        #---Detects Green Rectangle and sends area + error via UART---
        uart1.write("<" + str(Find_Green_Rect(img)) + "*")
    elif a == b'2':
        #---Detects Red Rectangle and sends area + error via UART---
        uart1.write("<" + str(Find_Red_Rect(img)) + "*")
    elif a == b'3':
        #---Measures brightness in the middle ROI and sends value via UART---
        uart1.write("<" + str(Find_MiddleBrightness(img)) + "*")
    elif a == b'4':
        #---Detects Orange Line and sends True/False via UART---
        uart1.write("<" + str(Find_Orange_Line(img)) + "*")
    elif a == b'5':
        #---Detects Blue Line and sends True/False via UART---
        uart1.write("<" + str(Find_Blue_Line(img)) + "*")

    #---Debugging: print the received UART command and FPS---
    print(a)
    print(clock.fps())
    time.sleep(0.01)  #Small delay for stability
```

## License 

```
GNU General Public License v3.0

Copyright (C) 2007 Free Software Foundation, Inc. <https://fsf.org/>

This program is free software: you can redistribute it and/or modify
it under the terms of the GNU General Public License as published
by the Free Software Foundation, either version 3 of the License, or
(at your option) any later version.

This program is distributed in the hope that it will be useful,
but WITHOUT ANY WARRANTY; without even the implied warranty of
MERCHANTABILITY or FITNESS FOR A PARTICULAR PURPOSE. See the
GNU General Public License for more details.

You should have received a copy of the GNU General Public License
along with this program. If not, see <https://www.gnu.org/licenses/>.

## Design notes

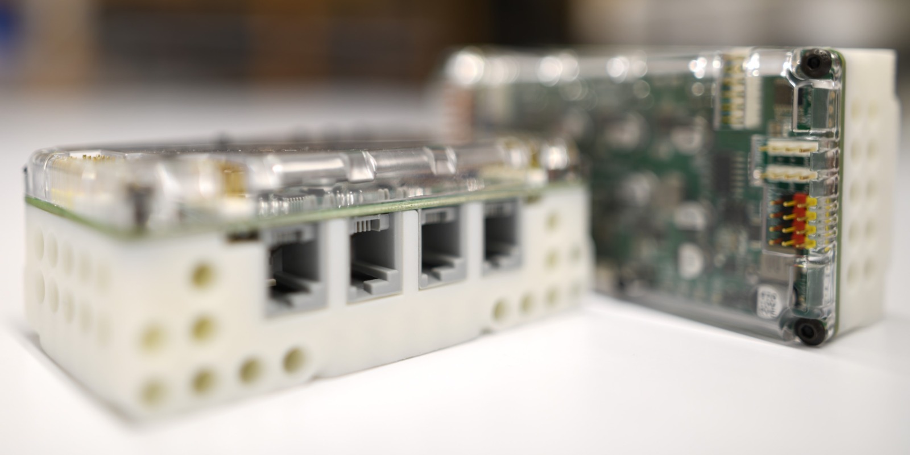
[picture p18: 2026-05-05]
other/evn/evn alpha2.jpg

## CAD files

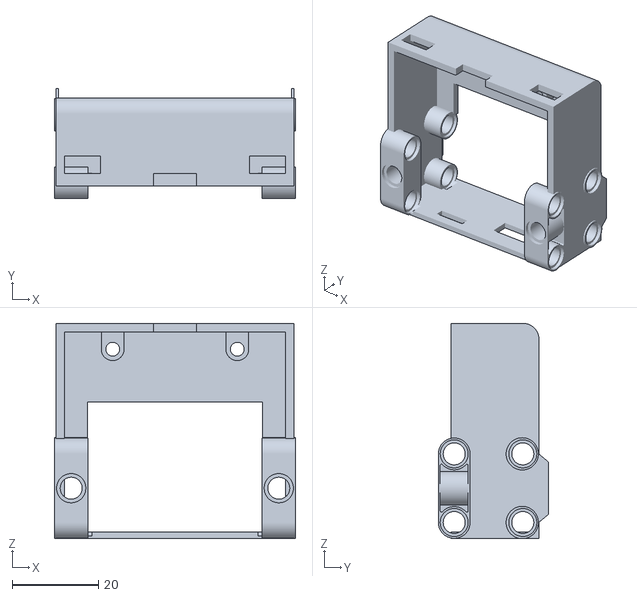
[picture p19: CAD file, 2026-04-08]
models/backpackOpenMV/backpackOpenMV.stl
56.0 x 25.6 x 50.0

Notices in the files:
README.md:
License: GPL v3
